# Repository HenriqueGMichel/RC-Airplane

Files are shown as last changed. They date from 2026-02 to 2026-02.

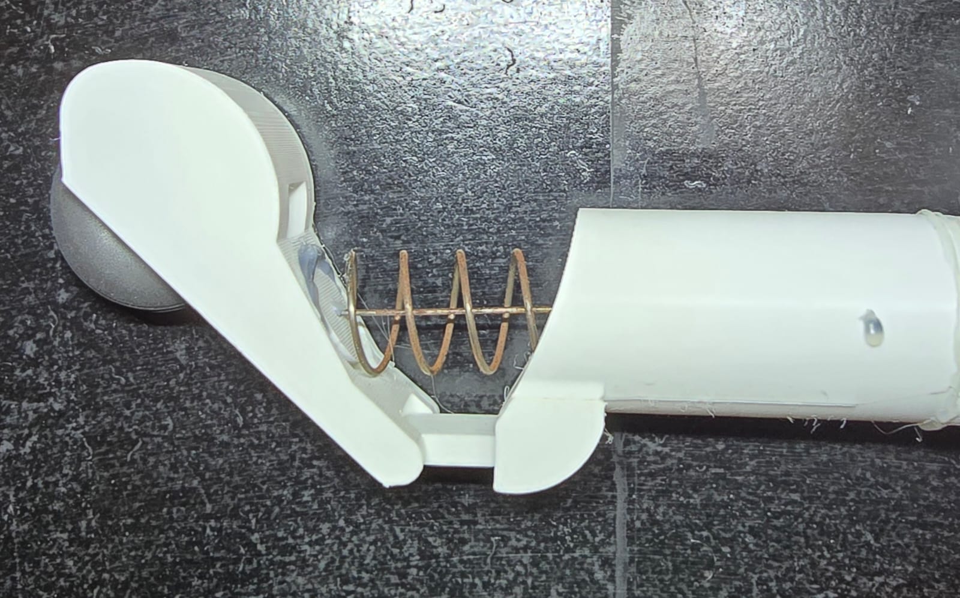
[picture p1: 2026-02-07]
3D Models/Landing Gear/Landing Gear Picture.jpeg

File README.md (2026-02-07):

# Custom RC Airplane: Hardware, Configs & 3D Parts

> **Note:** This project features an **F-22 Raptor** airframe (built from 4mm Depron). However, the documentation provided here electronics setup, EdgeTX configurations, and mechanical solutions—is **universal**. The concepts are not limited to this specific fuselage and can be adapted to almost any custom RC aircraft build.

Building a custom RC airplane often involves piecing together information from scattered sources finding the right electronics, figuring out radio mixes, and designing mechanical parts.

This repository aims to bridge that gap by centralizing the resources I used in my own build. It documents the integration of the RadioMaster ecosystem (EdgeTX/ELRS) with standard RC components, along with custom 3D modeled parts I designed to improve the airframe.

Whether you are an intermediate hobbyist or looking for specific configurations for the ER8 and Pocket, you will find practical, field-tested resources here.

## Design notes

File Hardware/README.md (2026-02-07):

#  Hardware Bill of Materials (BOM)

This project combines custom-built structural elements with off-the-shelf RC electronics. Below is the complete list of components used in the build.

##  Airframe & Structure
The fuselage and wings were scratch-built using lightweight foam sheets.

| Component | Specifications | Notes |
| :--- | :--- | :--- |
| **Fuselage Material** | Depron 4mm | Lightweight extruded polystyrene foam. |
| **Reinforcement** | Carbon Fiber Rods and Fiberglass | Used in the wings and tail for structural rigidity. |
| **Adhesives** | Hot Glue / Epoxy | Used for joining Depron sheets and mounting the motor firewall. |
| **Push Rods** | Steel Wire | Custom cut for control surface linkages. |

##  Propulsion System (Pusher Configuration)
The aircraft utilizes a rear-mounted motor setup.

| Component | Model | Configuration |
| :--- | :--- | :--- |
| **Motor** | D3536 Brushless | Rear-mounted, facing the tail. |
| **ESC** | Hobbywing Skywalker 50A V2 | 50Hz PWM, 5V/5A BEC. |
| **Propeller** | 10x6 | Mounted with numbers facing flight direction. |
| **Battery** | Li-Ion 4S (16.8V) | Custom pack for extended flight times. |

##  Electronics & Control
Based on the RadioMaster and ExpressLRS ecosystem.

| Component | Model | Role |
| :--- | :--- | :--- |
| **Transmitter (TX)** | RadioMaster Pocket | EdgeTX Operating System. |
| **Receiver (RX)** | RadioMaster ER8 | 2.4GHz ELRS PWM Receiver. |
| **Servos** | 9g Micro Servos (x4) | 1x Aileron R, 1x Aileron L, 1x Elevator R, 1x Elevator L. |

##  3D Printed Parts
Custom parts modeled to fit specific needs (STLs available in `3d_models/`).

* **Retractable Landing Gear:** Custom design with spring suspension.
* **Cockpit Canopy:** Aerodynamic profile fitted to the fuselage void.
* **Motor Mount:** Firewall adapter for the D3536 motor.

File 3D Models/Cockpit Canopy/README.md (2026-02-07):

#  Custom Cockpit Canopy

This is a basic cockpit model intended to serve as a reference or a base for your own designs.

## Design Process
To achieve a perfect fit with the fuselage, I used the following method:

1.  **Measurement:** I measured the dimensions (length, width, and height) of the "void space" available on the airplane fuselage where the cockpit sits.
2.  **Modeling:** Using **Fusion 360**, I created a solid block with the canopy's general aesthetic shape.
3.  **Boolean Operation:** I used the measured dimensions to make precise cuts (Boolean subtraction) on the model.

**Result:** The cockpit has the exact footprint required to snap into the fuselage while maintaining a streamlined aerodynamic profile.

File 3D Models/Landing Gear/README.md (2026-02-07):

# Custom Retractable Landing Gear

This landing gear was designed to be practical to build, easy to 3D print, and robust. It features a custom suspension system utilizing a steel spring sourced from AliExpress.

## Design Goals
- **Ground Clearance:** Designed for RC airplanes requiring at least **15cm** of clearance from the ground to accommodate rear propellers.
- **Modularity:** The main body consists of two parts to allow for movement and suspension travel.
- **Resourcefulness:** Modeled to utilize spare parts I already had from the airframe build.

## Bill of Materials (BOM)
Here are the non-printed parts required for assembly:

| Component | Specs | Usage |
| :--- | :--- | :--- |
| **Steel Spring** | 1.5mm wire Ø / 25mm external Ø | Provides the suspension tension. (Total Spring Min length: ~30mm, i cut in 3 parts of 80mm for each landing gear) |
| **Carbon Fiber Rod** | 2mm Ø | Acts as the hinge pin connecting Part 1 and Part 2. (Reused from airframe reinforcement) |
| **Push Rod** | Standard size | Cut to size for the central strut mechanism. |
| **Adhesives** | CA Glue (Super Glue) & Hot Glue | Used for general assembly and fixation. |

##  How it Works

### Suspension
The two-part printed body is hinged with the 2mm Carbon Fiber rod. The spring absorbs the impact during landing, protecting the fuselage.

### Retraction Mechanism
The retraction is actuated by a standard **9g Servo**.
* **Mechanism:** The servo rotates 90 degrees to release a tension thread, allowing the landing gear to deploy via the gear with the other servo.
* **Radio Setup:** On the RadioMaster Pocket, I configured two separate channels:
    1.  **Release Channel:** Controls the servo that releases the thread.
    2.  **Steering/Lock Channel:** Controls the gear direction (if steerable) or the secondary locking mechanism.

> **Note:** I currently do not have a video of the retractable assembly process, only a picture that i took when i made the first time.

I think there are a lot of things to improve in the project. One thing would be that you need at least 5 servo's.

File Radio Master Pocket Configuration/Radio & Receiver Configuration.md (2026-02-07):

#  Radio & Receiver Configuration

This document outlines the specific logic used to configure the **RadioMaster Pocket (EdgeTX)** and the **ER8 Receiver (ExpressLRS)**. The setup involves a complex mixing scheme to control dual ailerons and dual elevators independently.

##  Control Protocol Standards
* **Radio Firmware:** EdgeTX (Latest Stable)
* **RF Protocol:** ExpressLRS (ELRS) 2.4GHz
* **Channel Order:** AETR (Aileron, Elevator, Throttle, Rudder)

##  Channel Mapping Strategy
Due to the specific requirements of the airframe (Dual Elevator, Dual Aileron) and the ELRS Channel 5 limitation, the channels were mapped as follows:

| Channel | Function | Physical Connection | Logic/Mix Source |
| :--- | :--- | :--- | :--- |
| **CH1** | Aileron Right | ER8 Pin 1 | `Src: Ail` (100% Weight) |
| **CH2** | Elevator Right | ER8 Pin 2 | `Src: Ele` (100% Weight) |
| **CH3** | Throttle (ESC) | ER8 Pin 3 | `Src: Thr` (50Hz Output) |
| **CH4** | Elevator Left | ER8 Pin 4 | `Src: Ele` (Mirrored Mix) |
| **CH5** | **ARMING** | *No Servo* | `Switch: SA` (2-Pos Safety) |
| **CH6** | Aileron Left | ER8 Pin 6 | `Src: Ail` (Mirrored Mix) |

> **Note on CH5:** Channel 5 is strictly reserved for the Arm/Disarm state in ELRS. Therefore, the second Aileron was moved to Channel 6 to ensure proportional control.

##  Critical Settings

### 1. Dual Elevator Synchronization (Outputs)
Since the elevator servos are mounted physically mirrored, they initially moved in opposite directions (rolling the tail).
* **Fix:** In the **Outputs** tab, `CH4` direction was set to **INV** (Inverted).
* **Result:** Both surfaces move UP when the stick is pulled back (Pitch Up).

### 2. ESC Frequency Adjustment (Lua Script)
The **Skywalker 50A V2** ESC requires a standard PWM frequency.
* **Setting:** In the ExpressLRS Lua Script (`Other Devices` -> `ER8`), the **Output Mode** for Pin 3 was manually forced to **50Hz**.
* **Why:** Higher frequencies (100Hz+) caused the ESC to fail initialization (continuous beeping).

### 3. Input/Output Mapping
To ensure the servos on pins 4 and 6 responded to the correct mixes:
* **ER8 Mapping:** Verified via Lua Script that `Output Pin 4` -> `Input 4` and `Output Pin 6` -> `Input 6`.

### 4. Safety Features
* **Throttle Cut:** Configured on Switch `SA` (Up position overrides Throttle to -100%).
* **Failsafe:** Receiver configured to cut throttle (No Pulses/Low) in case of signal loss.

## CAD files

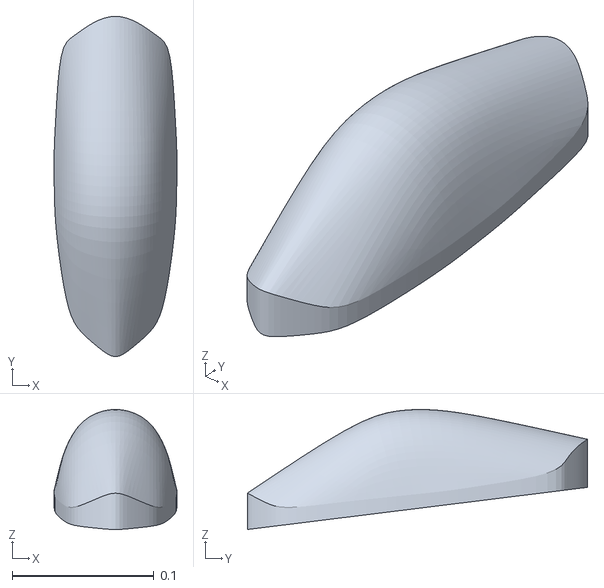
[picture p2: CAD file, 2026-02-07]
3D Models/Cockpit Canopy/Cockpit.stl
0.0868 x 0.24 x 0.0847

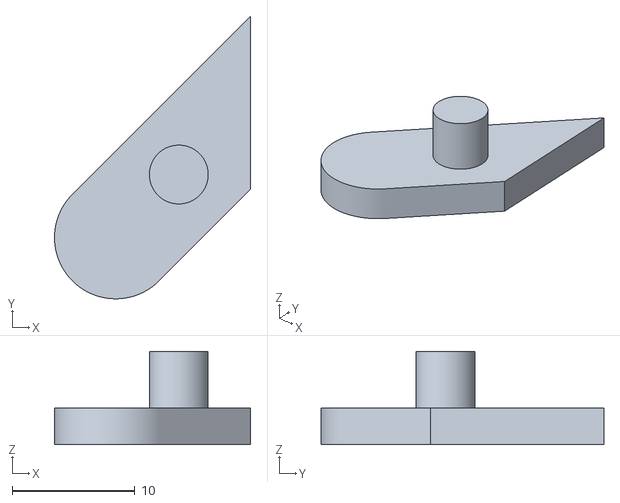
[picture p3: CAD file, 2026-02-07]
3D Models/Landing Gear/Part 5.stl
16.0 x 23.1 x 7.60

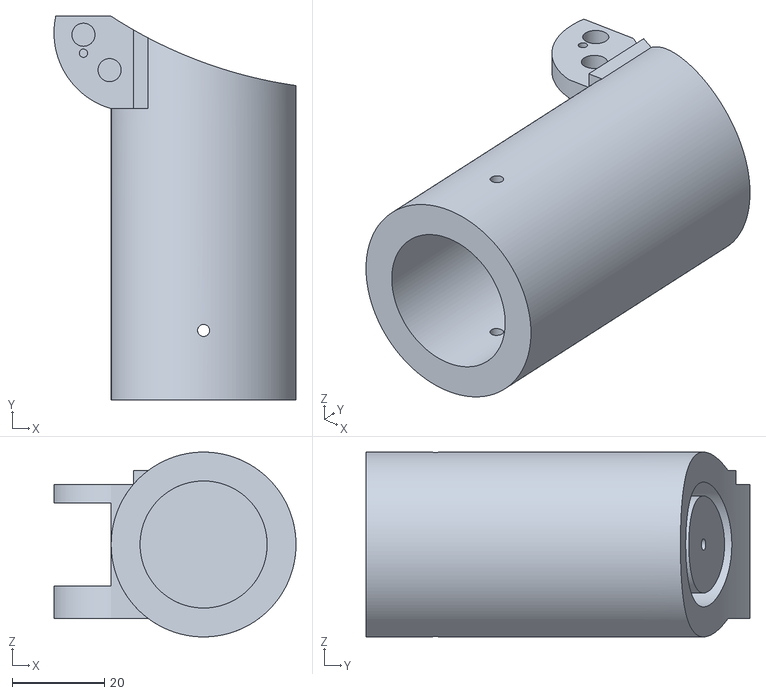
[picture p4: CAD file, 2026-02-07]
3D Models/Landing Gear/Part 2.stl
52.4 x 83.0 x 40.0

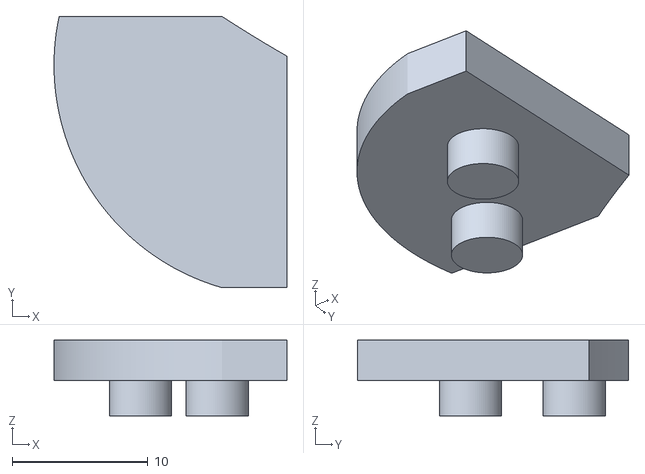
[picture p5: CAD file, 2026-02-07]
3D Models/Landing Gear/Part 4.stl
17.2 x 20.0 x 5.60

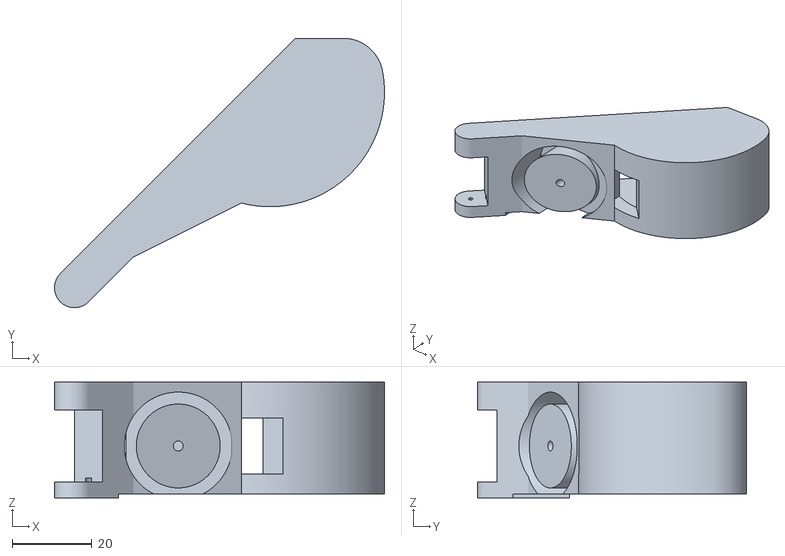
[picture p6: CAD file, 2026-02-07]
3D Models/Landing Gear/Part 7.stl
82.6 x 67.5 x 29.0

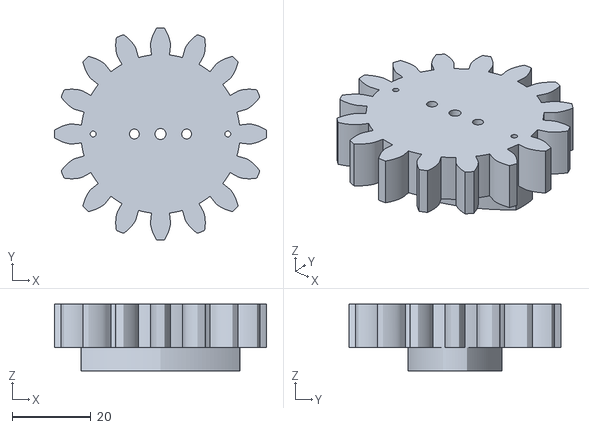
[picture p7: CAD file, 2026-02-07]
3D Models/Landing Gear/Part 10.stl
54.0 x 54.0 x 17.0

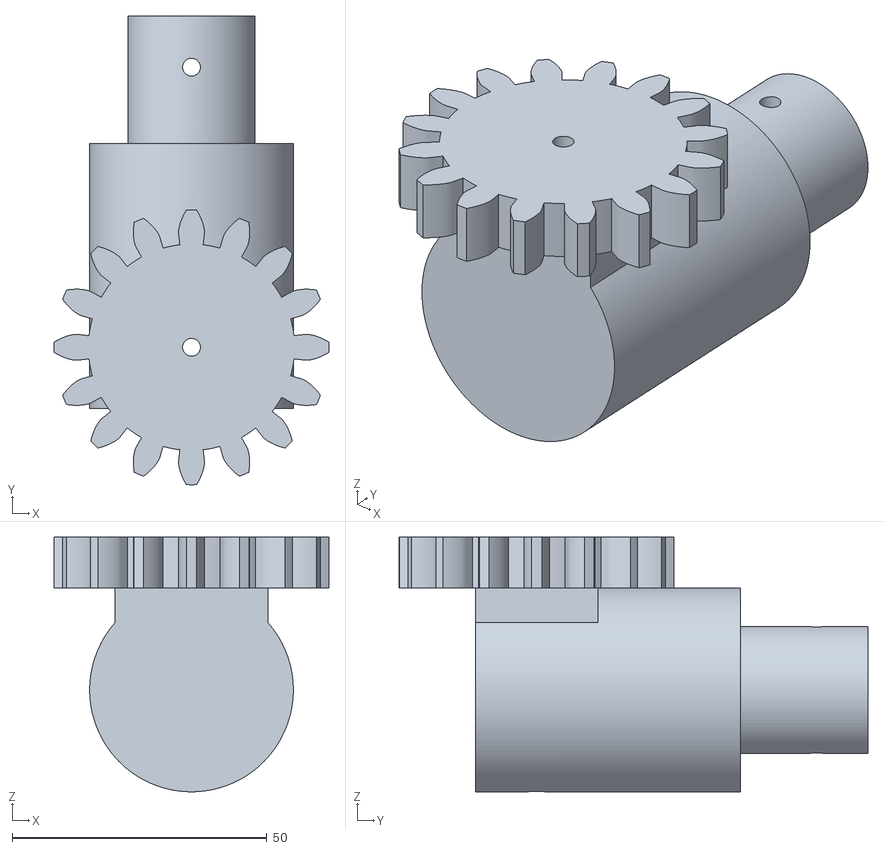
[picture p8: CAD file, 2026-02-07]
3D Models/Landing Gear/Part 1.stl
54.0 x 92.0 x 50.0

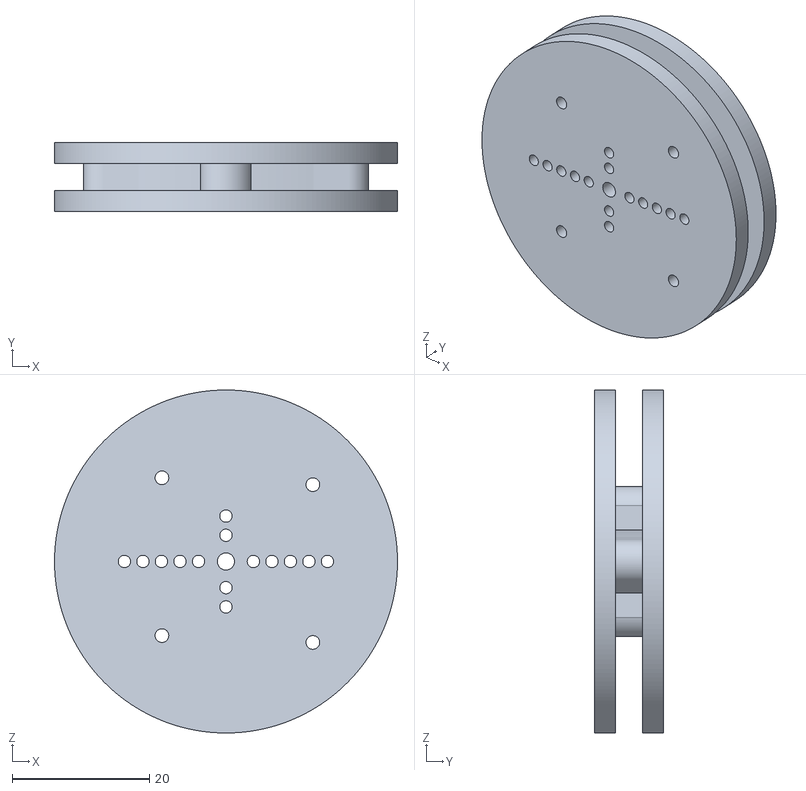
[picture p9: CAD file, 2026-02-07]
3D Models/Landing Gear/Part 13.stl
50.0 x 10.0 x 50.0

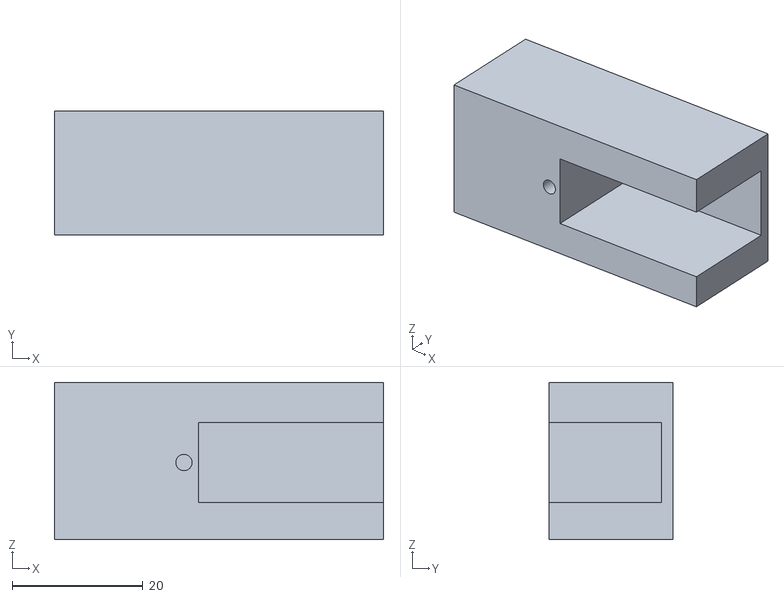
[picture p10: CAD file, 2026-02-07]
3D Models/Landing Gear/Part 12.stl
50.3 x 19.0 x 24.0

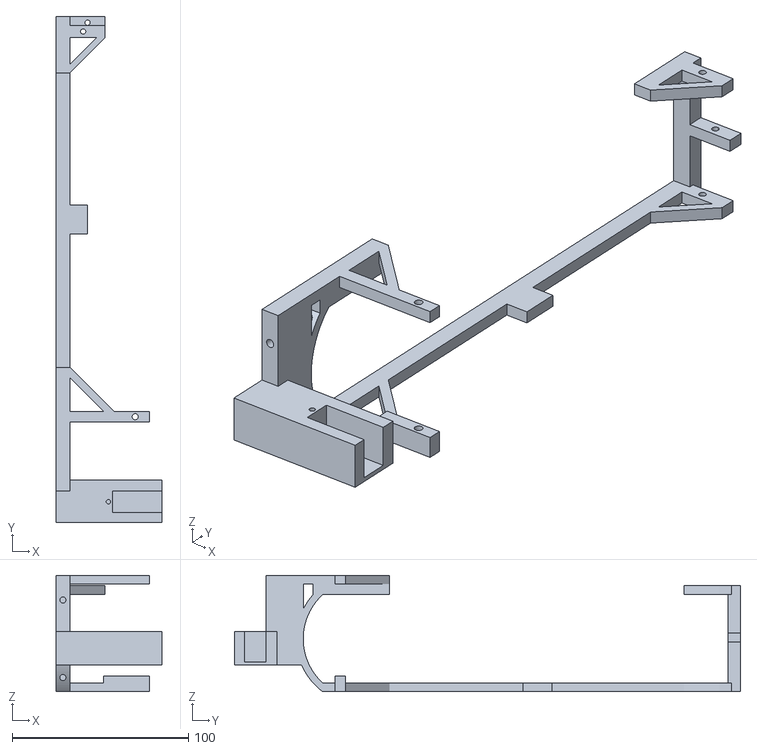
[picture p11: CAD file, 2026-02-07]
3D Models/Landing Gear/Part 11.stl
60.3 x 287.0 x 66.0

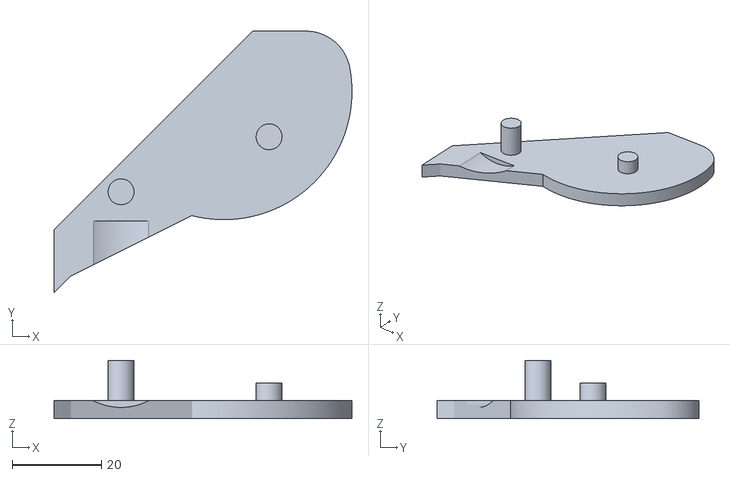
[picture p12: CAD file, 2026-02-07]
3D Models/Landing Gear/Part 8.stl
66.6 x 58.6 x 13.0

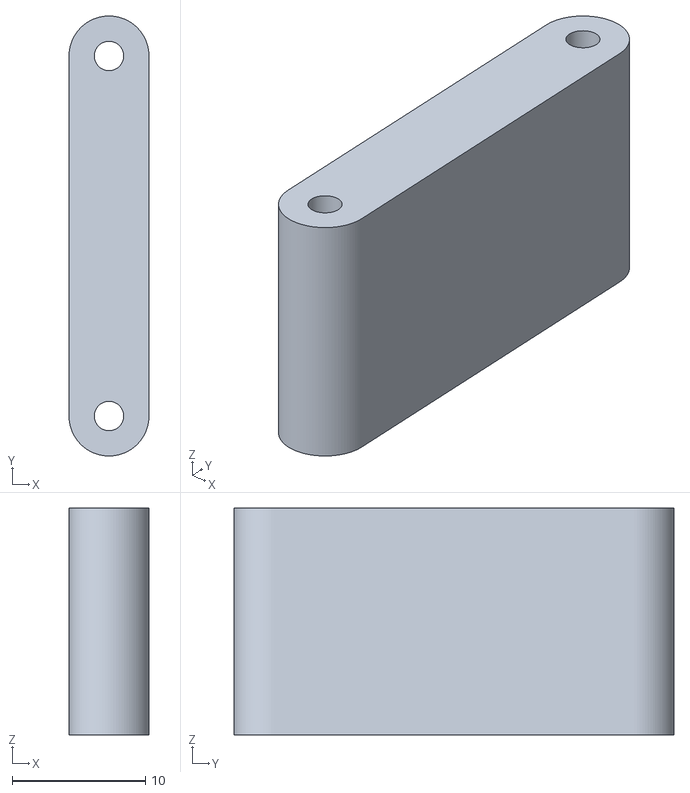
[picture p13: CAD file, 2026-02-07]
3D Models/Landing Gear/Part 3.stl
6.00 x 33.0 x 17.0

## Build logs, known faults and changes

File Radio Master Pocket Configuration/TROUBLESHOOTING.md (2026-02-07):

##  Configuration Challenges & Solutions

During the setup of the RadioMaster Pocket (EdgeTX) with the ER8 Receiver (ExpressLRS), several technical constraints were encountered. Below is a summary of the issues and the logic used to solve them.

### 1. ELRS Channel 5 Limitation (The "Stuck Servo" Issue)
* **Problem:** The servo connected to Channel 5 (intended for the second Aileron) was behaving erratically—locking to one side or not responding to proportional input.
* **Root Cause:** In the ExpressLRS protocol, Channel 5 is strictly reserved for the "Arming" state. It operates as a 1-bit switch (High/Low) and lacks the resolution required for PWM servo control.
* **Solution:** * Physically moved the second Aileron servo to **Channel 6**.
    * Updated the **EdgeTX Mixes**: Assigned `CH6` to source `Ail`.
    * Updated the **ER8 Output Mapping**: Ensured Pin 6 was mapped to Input 6.

### 2. Dual Elevator Synchronization
* **Problem:** The aircraft uses two independent servos for the elevator (tail). Initially, one surface moved up while the other moved down (acting like ailerons instead of elevators).
* **Root Cause:** The servos are physically mounted in a mirrored position, causing inverted mechanical movement for the same signal input.
* **Solution:** * Created a Mix on **CH4** sourcing from `Ele` (Elevator stick).
    * Used the **EdgeTX Outputs** tab to strictly **Invert (INV)** the signal of only one channel (CH4) to synchronize movement.
    * Adjusted the direction of both channels to ensure pulling the stick "back" resulted in "up" movement for pitch authority.

### 3. ESC Signal Frequency (Motor Beeping)
* **Problem:** The Skywalker 50A V2 ESC would not arm and kept beeping, despite the receiver being bound and showing telemetry.
* **Root Cause:** The modern ER8 receiver outputs high-frequency signals (100Hz/333Hz) by default, while the standard ESC expects a traditional **50Hz PWM** signal.
* **Solution:** * Accessed the ExpressLRS Lua Script -> `Other Devices` -> `RM ER8`.
    * Changed the **Output Mode** for Channel 3 (Throttle) to **50Hz**.

### 4. Input/Output Mapping Mismatch
* **Problem:** Control inputs were affecting the wrong surfaces (e.g., Throttle stick moving a servo).
* **Root Cause:** The internal mapping of the ER8 receiver was misaligned (Input 3 was routed to Physical Pin 4).
* **Solution:** * Audited the **Output Mapping** in the ELRS Lua Script.
    * Realigned all ports 1:1 (Input CH1 -> Output 1, Input CH2 -> Output 2, etc.) to match the EdgeTX Mixer standard.
